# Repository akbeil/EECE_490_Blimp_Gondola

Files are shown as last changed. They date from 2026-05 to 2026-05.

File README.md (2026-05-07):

# Helium Blimp Gondola

Anders Beil and Alessio Tourrilhes EECE 490B senior capstone project implementation. Project was undertaken as our senior undergraduate design project.

---
https://github.com/akbeil/EECE_490_Blimp_Gondola/blob/main/images/demo.mp4

<table align="center">
  <tr>
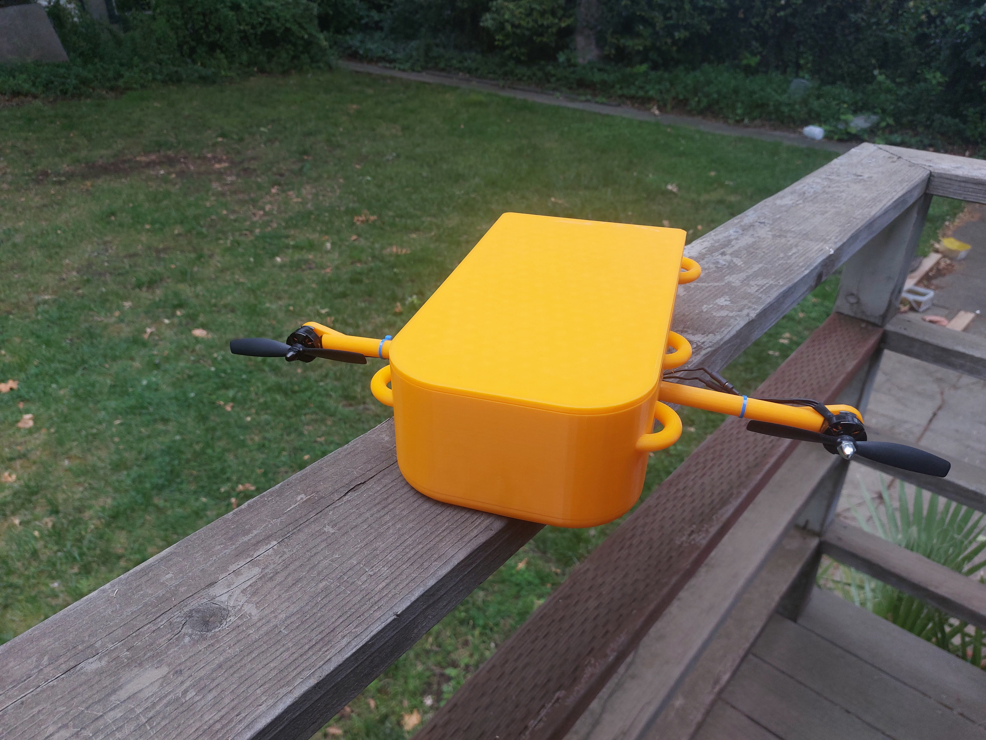
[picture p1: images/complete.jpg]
    <td></td>
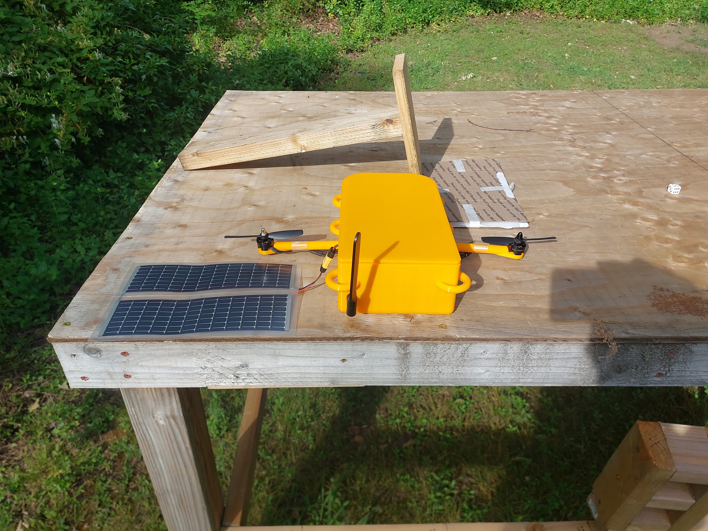
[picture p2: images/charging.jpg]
    <td></td>
  </tr>
  <tr>
    <td></td>
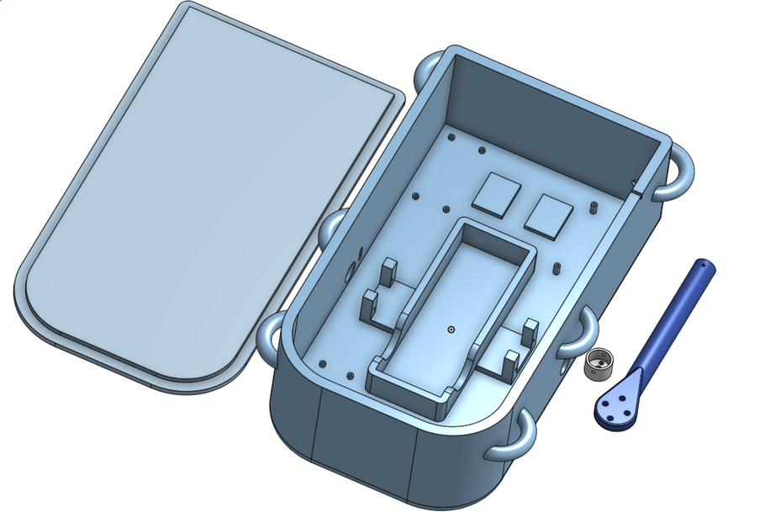
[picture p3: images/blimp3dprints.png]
    <td></td>
  </tr>
</table>

## Table of Contents
- [About](#about)
- [Features](#features)
- [Hardware](#hardware)
- [Software](#software)
- [Installation](#installation)
- [Contributors](#contributors)
---

## About

Current unmanned aerial vehicles (UAVs) have a gap in their capabilities. Drones are inexpensive but have limited flight duration, winged UAVs have longer flight times but come at a high cost. A small blimp UAV bridges this gap by being both affordable and capable of long duration flight. This blimp could be used for wildfire mapping, post-disaster search operations, or general area monitoring.

This projects object was to make the gondola that could then be attached to a blimp to be used as a surveilance blimp.

---

## Features

- Remote operation
- Receive commands via wireless LTE
- Magnetometer
- Image capture
- Configurable camera
- Battery powered with solar recharging
- Return home capeability 

---

## Hardware

Hardware needed to replicate project.
- Adafruit Ultimate GPS Breakout - PA1616S
- BNO055 9-axis Sensor
- Brushless ESC 2S 20A Electric Speed Controller
- CN3722 Solar MPPT Charger
- FEICHAO 2204 2300KV Brushless Motors
- Jx-2s-Jh10 BMS Board
- MG90D 270 Degree Servo Motors
- PCA9685 Servo Driver
- Raspberry Pi Camera Module 3
- Raspberry Pi Zero 2 W
- RC7.2-75 PSAF Solar Panels
- SIM7600G-H 4G HAT (B)
- Turnigy Rapid 2S2P 8000mAh Lipo Battery

Refer to gondola system layout in documents to build.

---

## Software

- Python 3
- adafruit_bno055
- adafruit_pca9685
- pygeomag
- pynmea2
- RClone
- rpicam
- mmcli

---

## Installation

OS settings
Ensure ModemManager Active
```bash
sudo systemctl enable ModemManager
sudo systemctl start ModemManager
```

In raspi-config
```bash
sudo raspi-config
```
Options:
Interface options
- ssh enabled
- I2C Enabled
- Serial port
  - The serial login shell is disabled
  - The serial interface is enabled

Create a venv to be able to use adafruit packages
```bash
python3 -m venv venv
source venv/bin/activate
```
install packages
```bash
sudo apt install rclone
sudo apt install modemmanager
sudo apt install libcamera-apps

pip install adafruit-blinka
pip install smbus2
pip install adafruit-circuitpython-bno055
pip install adafruit-circuitpython-pca9685
pip install pygeomag
pip install pynmea2
```

Make services for sripts to be ran automaticaly on startup
```bash
cd /etc/systemd/system/
nano servicename.service
```
Make 1 for each file thrustvector.py, recvfinal.py, and uploadfinal.py
```ini
Description=Blimp Startup Script
After=network.target

[Service]
User=<USER>
WorkingDirectory=<SCRIPT DIRECTORY>
ExecStart=<VENV PATH> <SCRIPT PATH>
Restart=always

[Install]
WantedBy=multi-user.target
```
Refer to test plan in documents to test components.

### Clone the Repository

```bash
git clone https://github.com/akbeil/EECE_490_Blimp_Gondola.git
```
## Contributors

- Anders Beil
     - akbeil@csuchico.edu  
- Alessio Tourrilhes
     - atourrilhes@csuchico.edu
     
### Advisor 
- Dr. Reza Khani
     - mkhani@csuchico.edu

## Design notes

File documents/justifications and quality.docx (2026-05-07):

Pi Zero 2W:

This is the microcontroller we chose. We chose it because it had enough ports for all the peripherals we need. Also it has good computational power for taking and compressing pictures as well as managing the control loops, while having reasonable power consumption.

Quality: satisfactory

Camera:

The camera is the central data component of our blimp and it must be working properly to be able to transmit the pictures we take from the gondola. Before the pictures are transmitted we want the camera to function properly. The camera is capable of capturing images in different resolutions and different compression quality. Both of these must be working to ensure that images the blimp captures are adjustable and able to be set how we want.

Quality: satisfactory

Solar Panels and MPPT charger:

The solar panels provide voltage to the charger, which charges the battery. This greatly extends the flight time.

Quality: passable, the charging is somewhat less than we had calculated

Brushless Motors:

The brushless motors and esc that control them are how the blimp navigates. They must be functioning correctly in order for the blimp to maneuver.

Quality: satisfactory

Servo Motors:

The servos control the orientation of the motors

Quality: satisfactory

LTE Board:

Cellular LTE is the main connection of the blimp while it is operating. It is how we will control the blimp and send commands to set settings and run programs. It is also how we upload data from the blimp, each image and then the metadata which include our gps location when the picture was taken.

Quality: satisfactory

BMS Board:

This board protects the battery from overcharge and undercharge. It also provides balanced charging from the MPPT charger.

Quality: problematic, the board is rated for 8a but the system requires more. There's no issues aside from motor start up delay.

GPS Board:

The gps is used to get the global position of the blimp, as well as altitude from sea level. It is critical for autonomous flight.

Quality: satisfactory

9 Axis Attitude Sensor:

The gyroscope is used to monitor the position, heading, and acceleration of the blimp. It uses a 3-axis accelerometer, 3-axis gyroscope, and 3-axis magnetometer. The most important part is the Euler angle which gives the direction the blimp is facing with respect to magnetic north. When combined with the gps the blimp knows where it is, and how it's moving.

Quality: satisfactory

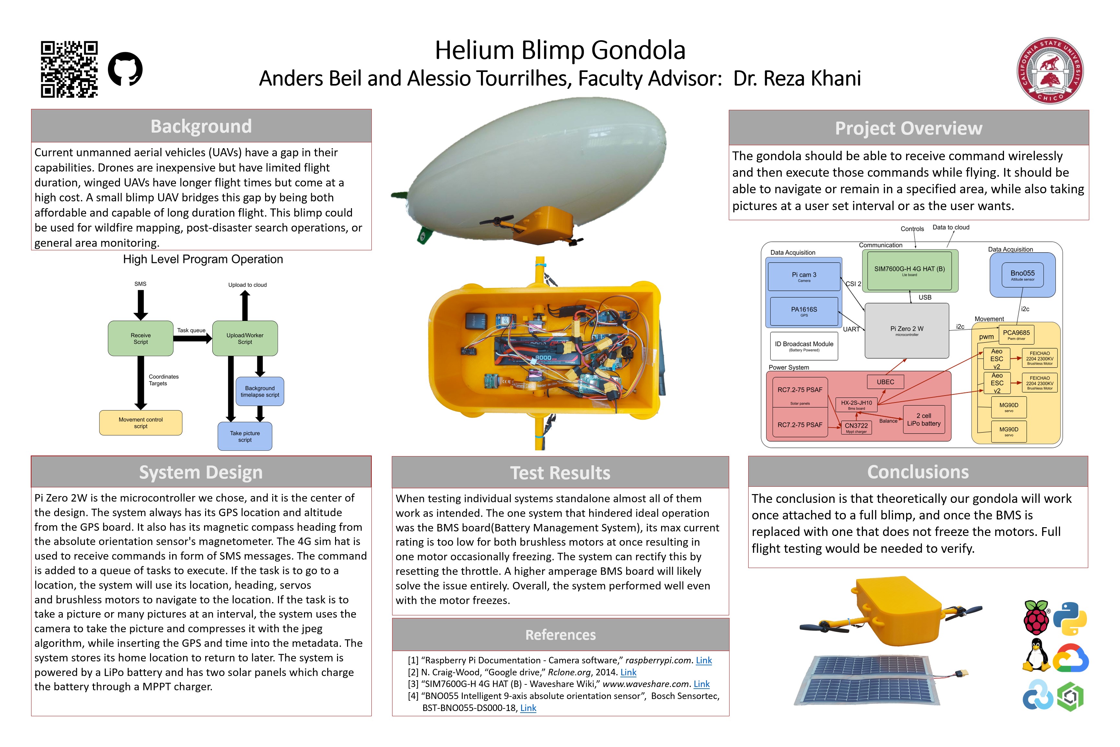
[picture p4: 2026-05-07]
documents/Slide1.jpg

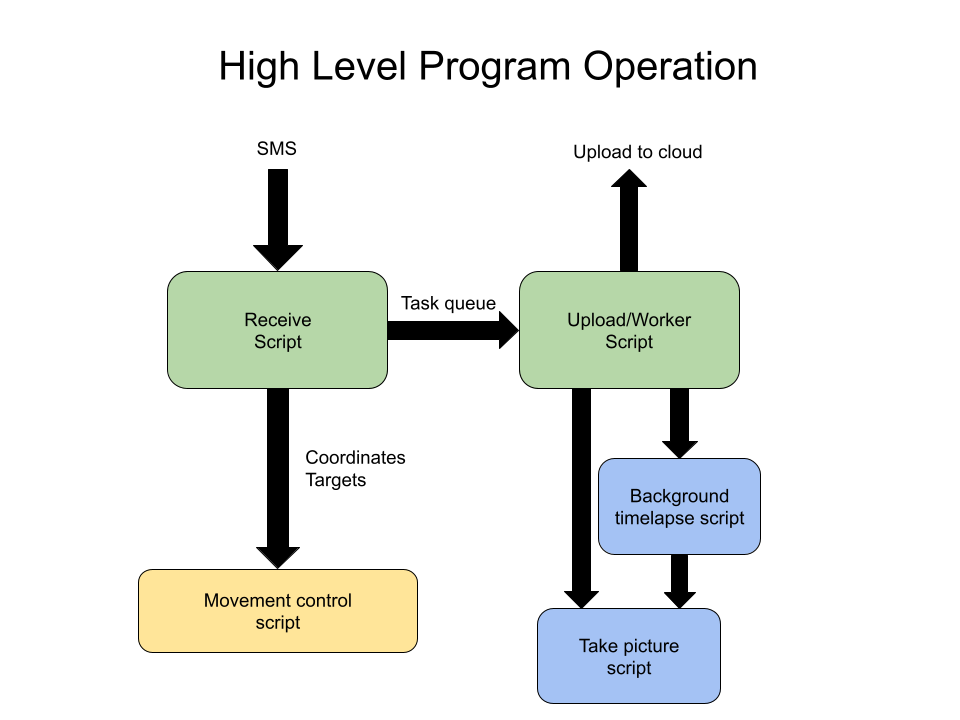
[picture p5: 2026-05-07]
documents/basic flowchart.png

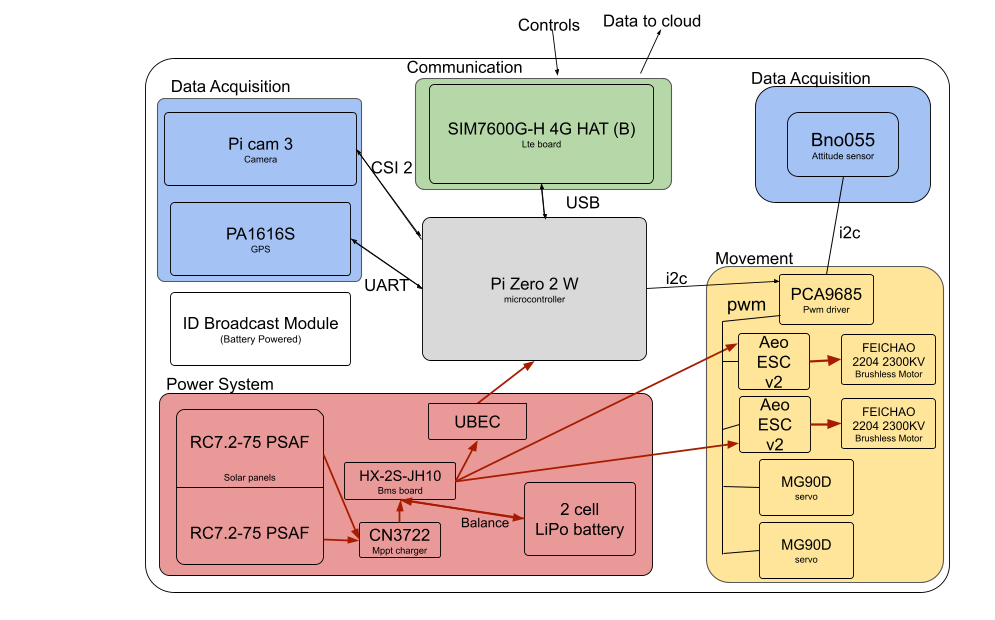
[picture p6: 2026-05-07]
documents/Gondola System Layout.png

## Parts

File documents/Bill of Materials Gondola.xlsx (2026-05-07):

Product | Quantiy | Price | Shipping | Website | Link
Adafruit Ultimate GPS Breakout - PA1616S | 1 | $29.95 | $5.80 | Adafruit | https://www.adafruit.com/wishlists/615395
Raspberry Pi Camera Module 3 | 1 | $31.99 | $0.00 | Adafruit | https://www.adafruit.com/wishlists/615395
CN3722 Solar MPPT Charger | 1 | $18.75 | $0.00 | Aliexpress | https://www.aliexpress.us/item/3256809700002675.html
SIM7600G-H 4G HAT (B) | 1 | $75.99 | $0.00 | Amazon | https://www.amazon.com/hz/wishlist/ls/3VE4V32JTM8RV?ref_=wl_share
Raspberry Pi Zero 2 W | 1 | $30.49 | $0.00 | Amazon | https://www.amazon.com/hz/wishlist/ls/3VE4V32JTM8RV?ref_=wl_share
Holy Stone FAA Compliant Remote Identification broadcast Module | 1 | $34.99 | $0.00 | Amazon | https://www.amazon.com/hz/wishlist/ls/3VE4V32JTM8RV?ref_=wl_share
3A 5V DC-DC Converter Step Down UBEC | 1 | $11.69 | $0.00 | Amazon | https://www.amazon.com/hz/wishlist/ls/3VE4V32JTM8RV?ref_=wl_share
Brushless ESC 2S 20A Electric Speed Controller | 2 | $18.99 | $0.00 | Amazon | https://www.amazon.com/hz/wishlist/ls/3VE4V32JTM8RV?ref_=wl_share
jx-2s-jh10 | 1 | $3.10 | $4.56 | AliExpress | https://www.aliexpress.us/item/3256804777549651.html
Turnigy Rapid 2S2P 8000mAh 7.4V 140C Lipo Battery | 1 | $20.60 | $10.02 | Hobby King | https://hobbyking.com/en_us/turnigy-rapid-8000mah-2s2p-140c-hardcase-lipo-battery-pack-roar-approved.html
RC7.2-75 PSAF | 2 | $19.99 | $7.03 | SolarMade | https://solarmade.com/checkouts/cn/hWN6YXK4aPnbgFvkiqrQm368/en-us
Teyleten Robot BNO055 9-Axis Attitude Sensor Module | 1 | $15.88 | $0.00 | Amazon | https://www.amazon.com/dp/B0D47G672B?ref=ppx_yo2ov_dt_b_fed_asin_title
MG90D 9g Digital Micro RC Servo Full Metal Gear 270 Degree | 2 | $4.25 | $0.00 | Amazon | https://www.amazon.com/dp/B0D5YBL2JX?ref=ppx_yo2ov_dt_b_fed_asin_title
FEICHAO 2204 2300KV Brushless Motor | 2 | $7.03 | $0.00 | Amazon | https://www.amazon.com/dp/B088K82Q46?ref=ppx_yo2ov_dt_b_fed_asin_title&th=1
 | items | 373.945
 | tax 9.25% | 34.59
 | shipping |  | $27.41
 | total | $435.94
RockBLOCK 9704 | 1 | $274.95 | $0.00 | SparkFun | https://www.sparkfun.com/rockblock-9704-patch-antenna.html
 | items | 648.895
 | tax 9.25% | 60.02
 | shipping |  | $27.41
 | total | $736.33

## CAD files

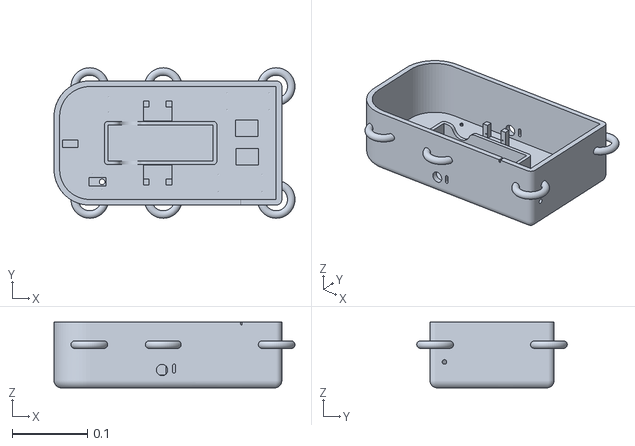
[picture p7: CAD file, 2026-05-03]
3d models/Gondola.stl
0.32 x 0.2 x 0.0875

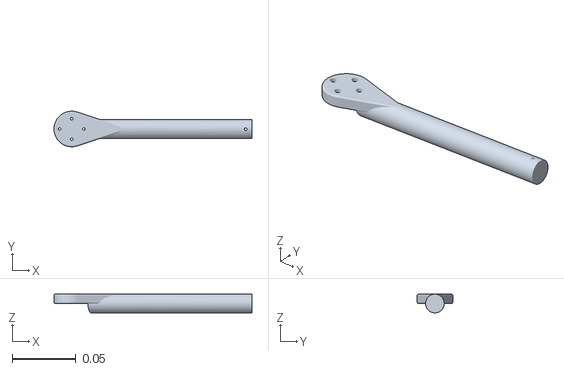
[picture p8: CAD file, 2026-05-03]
3d models/pole.stl
0.155 x 0.028 x 0.0148

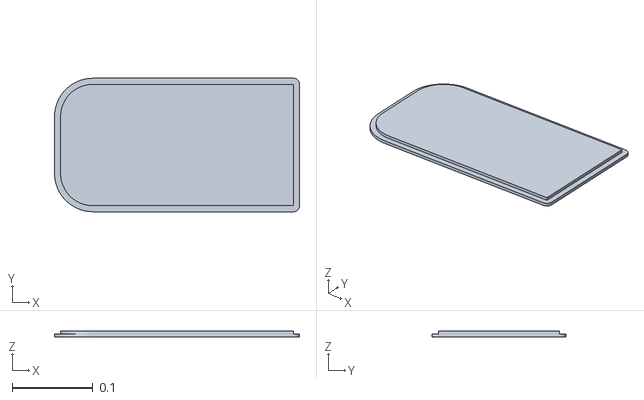
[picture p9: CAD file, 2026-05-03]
3d models/Lid.stl
0.303 x 0.165 x 0.0075

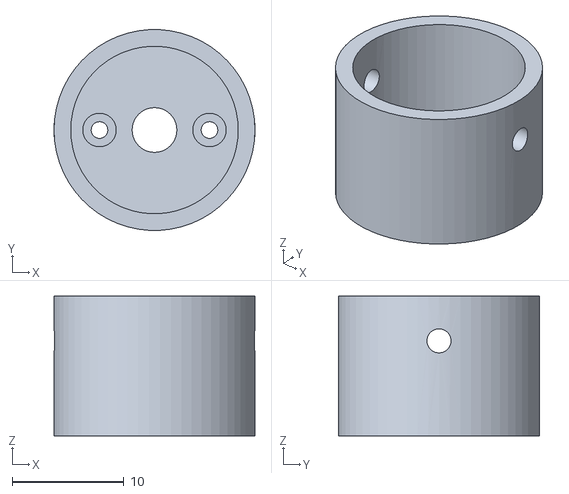
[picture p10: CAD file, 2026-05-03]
3d models/Servo attachment.stl
18.0 x 18.0 x 12.5

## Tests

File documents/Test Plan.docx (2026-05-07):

Test #1 Camera

The camera is the central data component of our blimp and it must be working properly to be able to transmit the pictures we take from the gondola. Before the pictures are transmitted we want the camera to function properly. The camera is capable of capturing images in different resolutions and different compression quality. Both of these must be working to ensure that images the blimp captures are adjustable and able to be set how we want.

Materials Needed for Test:

- Raspberry Pi Zero 2 W
- Raspberry Pi Camera Module 3
- Command Prompt / Pi Connect

Performing the Test:

1. The first thing that must be done for the test is to connect to the pi, either by ssh or Pi Connect.

ssh blimp26@RASPBERRY_PI's_IP_ADDRESS

2. Next ensure that you are in the correct directory with

cd /home/blimp26/0405

3. There are 3 parameters for takepic.py. The first is resolution which can be set to 720, 1080, or 4k. The second is quality that can be set from 0-100 and control the compression of the image. Closer to 0 gets you a smaller file size but at the cost of image quality. And the reverse for closer to 100.

python3 takepic.py 720|1080|4k quality filename.jpg

4. We will want to ensure that all levels of resolution work with a range of compressions
5. First we can do.

python3 takepic.py 720 100 testcamera720_100.jpg

6. Next do.

python3 takepic.py 720 50 testcamera720_50.jpg

7. Lastly for 720p.

python3 takepic.py 720 25 testcamera720_25.jpg

8. We will use SFTP as an easy way to transfer files from the pi to a separate computer for viewing as the pi is headless and must be accessed via SSH. First connect to pi from laptop using

sftp blimp26@RASPBERRY_PI's_IP_ADDRESS

9. Using SFTP is like using linux commands, ls, cd, pwd, mkdir, rm, rmdir all work, using this navigate to the folder where picture were taken in this case

ls

cd 0405

10. Then using SFTP from a computer we can transfer the image to a device that has a visual interface to inspect the images visually to see the difference in image quality while also inspecting the image size. Once you are in the directory of files you want then you just get and specify where you want to put the file on the computer and it transfers the file.

get [directory/file on pi] [local directory]

get testcamera720_25.jpg C:/user/Pictures

11. Repeat step 10 for all images taken.
12. Then repeat steps 5 through 11 for resolutions of 1080p and 4k. Those commands would be as follows for 1080p.

python3 takepic.py 1080 100 testcamera1080_100.jpg

python3 takepic.py 1080 60 testcamera1080_60.jpg

python3 takepic.py 1080 20 testcamera1080_20.jpg

get testcamera1080_100.jpg C:/user/Pictures

get testcamera1080_60.jpg C:/user/Pictures

get testcamera1080_20.jpg C:/user/Pictures

13. And commands for 4k would be as follows.

python3 takepic.py 4k 100 testcamera4k_100.jpg

python3 takepic.py 4k 65 testcamera4k_65.jpg

python3 takepic.py 4k 30 testcamera4k_30.jpg

get testcamera4k_100.jpg C:/user/Pictures

get testcamera4k_65.jpg C:/user/Pictures

get testcamera4k_30.jpg C:/user/Pictures

14. And quality can be used across all 3 resolutions. We are just trying to ensure that quality works across all 3 and compression works to compress images and give us a smaller file and then can see the difference in quality of different compression levels.
15. End of Test.

Results:

Camera is able to be configured and a wide range of resolutions and quality are able to be produced, leading to a successful system that serves our needs for next block of the system.

Script: takepic.py

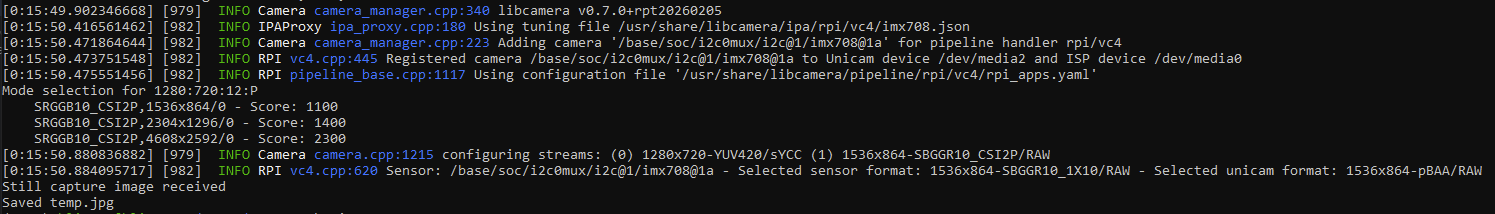
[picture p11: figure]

Test #2 Solar Pannel

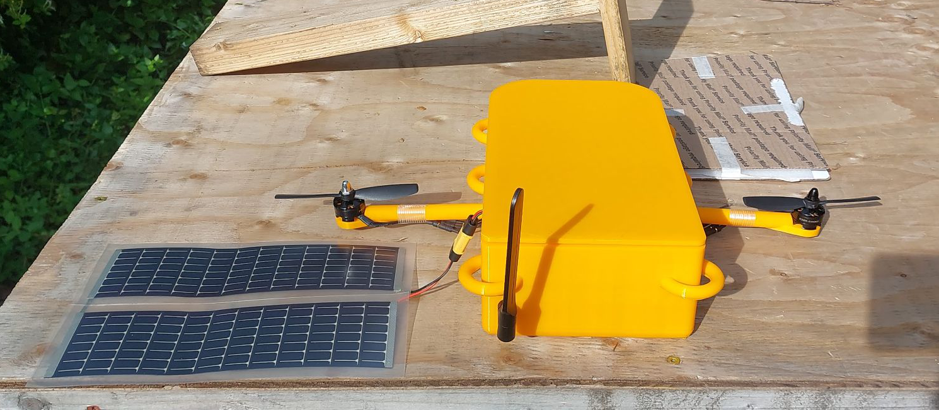
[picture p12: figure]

Materials Needed for Test:

- 2x of RC7.2-75 PSAF in Series
- CN3722 Solar MPPT Charger
- Multi Meter

Performing the Test:

1. First ensure that solar panels in series are working and giving an output. VOC = 11.1V and Operating voltage is 7.2v so depending on the sun levels ensure that the voltage is between 14.4V-22.2V. If covering the panel reduces voltage then the panel is operating correctly. The more sun the higher the voltage should be.
2. Connect solar panel. If there is no output, counterclockwise adjust the MPPT pot until voltage appears.

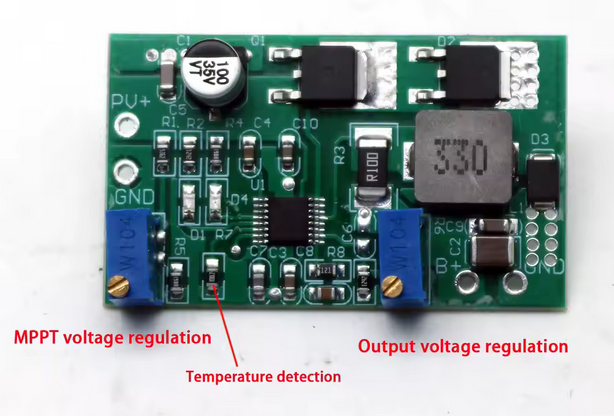
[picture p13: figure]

3. Counterclockwise adjust output pot until LEDs blink, then set to the battery’s max voltage of 8.4V.
4. Connect battery + ammeter. Fine-tune MPPT pot for max current (or match solar panel’s nominal voltage).
5. Verify cutoff voltage with multimeter and adjust output pot if needed.
6. End Test.

Results:

The MPPT board outputs 8.4V which will allow the battery to be trickle charged to extend the duration of the gondola’s operation.

Test #3 Motors

The brushless motors and esc that control them are how the blimp navigates. They must be functioning correctly in order for the blimp to maneuver.

Materials Needed for Test:

- Raspberry Pi Zero 2 W
- 2x of FEICHAO 2204 2300KV Brushless Motor
- 2x of EPower 20A 2S ESC
- PCA9685 I2C PWM board
- Command Prompt / Pi Connect
1. The first thing that must be done for the test is to connect to the pi, either by ssh or Pi Connect.
2. Next ensure that you are in the correct directory with

cd /home/blimp26/blimp_venv

3. Next activate the virtual python environment if not already active

source venv/bin/activate

4. The pwm board allows control of many pwm outputs using i2c
5. The test script allows to test the motors
  a. Set motors to MINIMUM to arm the ESCs

If not, entering program mode is possible

if that is the case, do not change throttle level and disconnect ESCs

  b. After the 12 123 beep chime you can test freely

Script: python programesc.py

6. End Test.

Results:

The motors' full range of rpms are accessible and working as intended. This allows us to control the blimp as we desire and at more specific throttle levels than this test if we choose to.

Test #4 Servo Motors

The servos control the orientation of the motors

Materials Needed for Test:

- Raspberry Pi Zero 2 W
- 2x of MG90D 270° Servo Motors
- PCA9685 I2C PWM board
- Command Prompt / Pi Connect
1. The first thing that must be done for the test is to connect to the pi, either by ssh or Pi Connect.
2. Next ensure that you are in the correct directory with

cd /home/blimp26/blimp_venv

3. Next activate the virtual python environment if not already active

source venv/bin/activate

4. The test script allows to test the servos
  a. The ESCs need to be plugged in as they provide power to the servos

Script: python servoctrl.py

5. End of test

Results

The servo motors can move the arms adequately and have good precision. They can be set to any point in 270 degrees of rotation.

Test #5 LTE

Cellular LTE is the main connection of the blimp while it is operating. It is how we will control the blimp and send commands to set settings and run programs. It is also how we upload data from the blimp, each image and then the metadata which include our gps location when the picture was taken.

Materials Needed for Test:

- Raspberry Pi Zero 2 W
- SIM7600G-H 4G HAT (B)
- Command Prompt / Pi Connect
1. The first thing that must be done for the test is to connect to the pi, either by ssh or Pi Connect.
2. The modem manager and network manager automatically detect the lte board and configure the network interface.
3. If needed it can be done manually with the following commands and qmi command line interface
  a. sudo systemctl disable ModemManager
  b. sudo qmicli -d /dev/cdc-wdm0 --wds-start-network="apn=simbase,ip-type=4" --client-no-release-cid
  c. sudo qmicli -d /dev/cdc-wdm0 --wds-get-current-settings --client-no-release-cid --client-cid=[cid]
  d. sudo ip link set dev wwan0 up
  e. sudo ip a add [addr] dev wwan0 metric 700
  f. sudo ip route add default via [gate] dev wwan0 metric 700
4. Check the modemmanager assigned an ip correctly

Command: ip address

5. Check the status of the connection

Command: mmcli -m 0

6. Test the connection by pinging using the lte network interface

ping -I wwan0 -c 1 8.8.8.8

7. End of test

Results

Modem manager is correctly set up to automatically configure the lte/wwan0 network interface, and transmission speed and latency are acceptable.

Test #6 Gps

The gps is used to get the global position of the blimp, as well as altitude from sea level. It is critical for autonomous flight.

Materials Needed for Test:

- Raspberry Pi Zero 2 W
- PA1616S GPS
- Command Prompt / Pi Connect
1. The first thing that must be done for the test is to connect to the pi, either by ssh or Pi Connect.
2. Next ensure that you are in the correct directory with

cd /home/blimp26/blimp_venv

3. Next activate the virtual python environment if not already active

source venv/bin/activate

4. The test script outputs the coordinates and altitude

Script: python gpstest.py

Taking the coordinates to google maps shows position accurately to a 5 meters. The system is in the backyard.

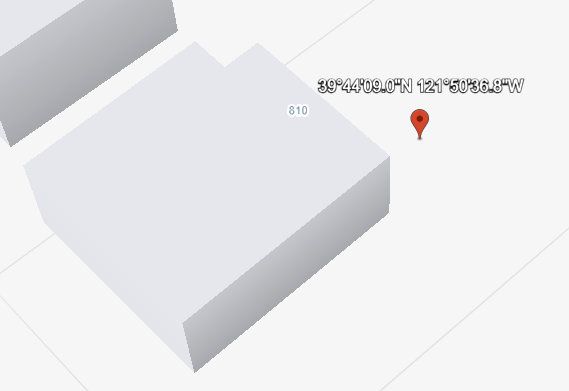
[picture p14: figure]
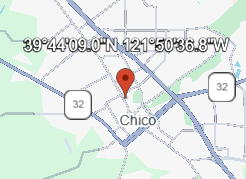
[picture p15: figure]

5. End of test

Results

The gps module is very accurate and important for the navigation of the blimp.

Test #7 9 Axis Attitude Sensor

The gyroscope is used to monitor the position, heading, and acceleration of the blimp. It uses a 3-axis accelerometer, 3-axis gyroscope, and 3-axis magnetometer. The most important part is the euler angle which gives the direction the blimp is facing with respect to magnetic north. When combined with the gps the blimp knows where it is, and how it's moving.

Materials Needed for Test:

- Raspberry Pi Zero 2 W
- BNO055 Absolute Orientation Sensor
- Command Prompt / Pi Connect
1. The first thing that must be done for the test is to connect to the pi, either by ssh or Pi Connect.
2. Next ensure that you are in the correct directory with

cd /home/blimp26/blimp_venv

3. Next activate the virtual python environment if not already active

source venv/bin/activate

4. The test script outputs all the data the bno055 collects

Script: python bno055test.py

The board needs to be moved around briefly for it to calibrate.

The first number of euler angle, which is the surface plane angle relative to north, is accurate to a couple of degrees.

5. End of test

Results

The bno055 is very accurate and important for the navigation of the blimp.

Test #8 Cloud upload

Materials Needed for Test:

- Raspberry Pi Zero 2 W
- Command Prompt / Pi Connect
1. The first thing that must be done for the test is to connect to the pi, either by ssh or Pi Connect.
2. Next ensure that you are in the a directory with a file
3. The rclone command is used to upload files to the google cloud folder. The -v tag is to show a verbose output of the command.

Command: rclone copy [file name] blimp26:/BlimpImages -v

The file correctly appears in the cloud folder

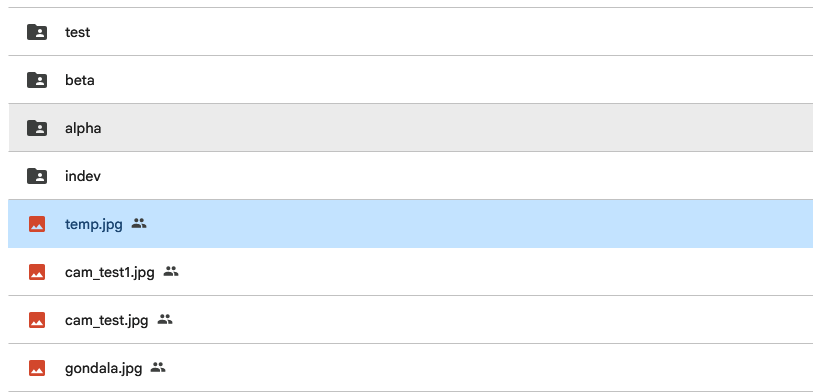
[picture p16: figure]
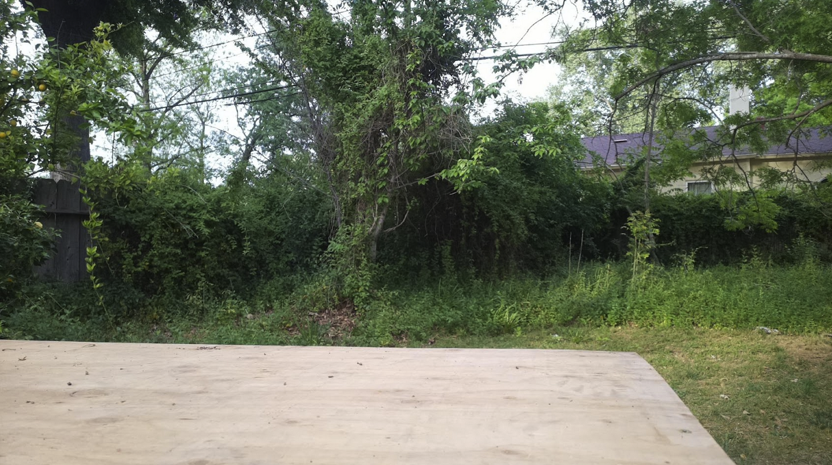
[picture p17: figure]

4. End of test

Results

The file is transferred accurately over lte to the cloud folder.

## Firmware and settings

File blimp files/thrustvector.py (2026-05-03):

import math
import time
import board
import busio
import serial
import pynmea2
from adafruit_bno055 import BNO055_I2C
from adafruit_pca9685 import PCA9685
from pygeomag import GeoMag
geomag = GeoMag()

GPS_PORT = "/dev/serial0"
GPS_BAUD = 9600
GPS_TIMEOUT = 10

SERVO_NEUTRAL = 1500
SERVO_MIN = 500
SERVO_MAX = 2500
DEADBAND = 5

SERVO_CH = [7, 8]
ESC_CH = [0, 1]

PCA_FREQ = 50 # Hz for standard servos / ESCs

def get_latest_gps(ser):
    """read latest GPS fix"""
    while ser.in_waiting:
        line = ser.readline().decode(errors="ignore").strip()

        if line.startswith("$GPGGA"):
            try:
                msg = pynmea2.parse(line)
                if int(msg.gps_qual) > 0:
                    return {
                        "lat": msg.latitude,
                        "lon": msg.longitude,
                        "alt": float(msg.altitude)
                    }
            except Exception:
                pass

    return None

def get_bearing(lat1, lon1, lat2, lon2):
    """get bearing from point 1 to point 2 in degrees (0-360)"""
    lat1 = math.radians(lat1)
    lat2 = math.radians(lat2)
    dlon = math.radians(lon2 - lon1)

    x = math.sin(dlon) * math.cos(lat2)
    y = math.cos(lat1)*math.sin(lat2) - math.sin(lat1)*math.cos(lat2)*math.cos(dlon)

    bearing = math.degrees(math.atan2(x, y))
    return (bearing + 360) % 360

def heading_error(target, current):
    """compute heading error (-180 to 180)"""
    error = target - current
    if error > 180:
        error -= 360
    elif error < -180:
        error += 360
    return error

def distance_m(lat1, lon1, lat2, lon2):
    """distance between two lat/lon points in meters"""
    R = 6371000  # Earth radius (m)

    lat1 = math.radians(lat1)
    lat2 = math.radians(lat2)
    dlat = lat2 - lat1
    dlon = math.radians(lon2 - lon1)

    a = math.sin(dlat / 2)**2 + math.cos(lat1) * math.cos(lat2) * math.sin(dlon / 2)**2
    c = 2 * math.atan2(math.sqrt(a), math.sqrt(1 - a))

    return R * c

def thrust_vector_control(error, alt_error, pca):
    abs_err = abs(error)
    direction = 1 if error > 0 else -1  # +1 = right turn, -1 = left

    base_throttle = 1100
    min_throttle = 1000
    max_throttle = 1200
    forward = 32

    if alt_error > 5:
        forward = 17
    elif alt_error < -5:
        forward = 47
    else:
        forward = 32

    # straight
    if abs_err <= 10:
        set_servo_pair(forward, pca)
        set_pulse(ESC_CH, base_throttle, pca)
        return

    # 10 to 90
    elif abs_err <= 90:
        #t = (abs_err - 10) / (90 - 10)  # 0 → 1

        active = base_throttle
        reduced = 1000 #base_throttle - t * (base_throttle - min_throttle)

        set_servo_pair(forward, pca)

        if direction > 0:
            # turn right
            set_pulse(ESC_CH[0], active, pca)
            set_pulse(ESC_CH[1], reduced, pca)
        else:
            # turn left
            set_pulse(ESC_CH[0], reduced, pca)
            set_pulse(ESC_CH[1], active, pca)

        return

    # 90 to 180
    else:
        #t = (abs_err - 90) / (180 - 90)  # 0 → 1

        #ramp = min_throttle + t * (max_throttle - min_throttle)

        if direction > 0:
            # turn right
            set_pulse(ESC_CH[0], base_throttle, pca)
            set_pulse(ESC_CH[1], base_throttle, pca)

            set_pulse(SERVO_CH[1], 2500, pca)
            set_pulse(SERVO_CH[0], 2500-2000*0.32, pca)

        else:
            # turn left
            set_pulse(ESC_CH[0], base_throttle, pca)
            set_pulse(ESC_CH[1], base_throttle, pca)

            set_pulse(SERVO_CH[0], 500, pca)
            set_pulse(SERVO_CH[1], 2000*0.32+500, pca)

        return

def set_pulse(channels, pulse_us, pca):
    """Set PWM pulse width for PCA9685"""
    duty = int(pulse_us / (1000000 / PCA_FREQ) * 65535)
    if isinstance(channels, int):
        pca.channels[channels].duty_cycle = duty
    else:
        for ch in channels:
            pca.channels[ch].duty_cycle = duty

servo_ch = [7,8]
def set_servo_pair(percent, pca):
    """set both servos to a percent 0 down 100 backwards"""
    percent = max(0, min(100, percent))

    min_pulse = 500
    max_pulse = 2500
    step = (max_pulse - min_pulse) / 100

    pulse1 = int(min_pulse + percent * step)
    pulse2 = int(max_pulse - percent * step)

    pca.channels[servo_ch[1]].duty_cycle = int(pulse1 / 20000 * 65535)
    pca.channels[servo_ch[0]].duty_cycle = int(pulse2 / 20000 * 65535)

def main():
    TARGET_LAT = None
    TARGET_LON = None
    TARGET_ALT = None
    TARGET_RAD = None
    HOME_LAT = None
    HOME_LON = None
    HOME_ALT = None

    # i2c
    i2c = busio.I2C(board.SCL, board.SDA)

    # bno055
    sensor = BNO055_I2C(i2c, address = 0x29)
    sensor.mode = 12

    # pca9685
    pca = PCA9685(i2c, address = 0x40)
    pca.frequency = PCA_FREQ

    # gps
    ser = serial.Serial(GPS_PORT, GPS_BAUD, timeout=0.2)

    # bno055
    while not ((sensor.calibration_status[3] == 3) & (sensor.calibration_status[0] == 3)):
        print("mag status: ", sensor.calibration_status[3], ", sys status: ", sensor.calibration_status[0])
        time.sleep(0.5)

    print("starting nav loop")
    set_servo_pair(31, pca)
    time.sleep(0.5)
    set_servo_pair(32, pca)
    set_pulse(ESC_CH, 1000, pca)
    time.sleep(5)
    booldec = False
    head_error = 9999
    declination = 0
    check = 10

    while True:
        gps = get_latest_gps(ser)
        if gps is None:
            print("no gps")
            time.sleep(1)
            continue
        
        # set home coords
        if gps is not None and HOME_LAT is None:
            HOME_LAT = gps["lat"]
            HOME_LON = gps["lon"]
            HOME_ALT = gps["alt"]
            with open("home.txt", "w") as h:
                h.write(f"{HOME_LAT},{HOME_LON},{HOME_ALT}")
            print("home set:", HOME_LAT, HOME_LON, HOME_ALT)

        # calculate declination
        if gps is not None and (not booldec):
            declination = geomag.calculate(gps["lat"], gps["lon"], gps["alt"], 2026.25).dec
            print ("declination: ", declination)
            booldec = True
        
        mag_heading = sensor.euler[0]
        
        if mag_heading is None:
            print("waiting for bno heading")
            time.sleep(0.1)

        # no gps for 5sec stop motors
        last_valid_time = time.time()
        if gps:
            last_valid_time = time.time()

        if time.time() - last_valid_time > 5:
            print("failsafe: stopping motors")
            set_pulse(ESC_CH, 1000, pca)
        
        # check for updates to target file
        if (check > 10):
            check = 0
            try:
                with open("target.txt") as f:
                    line = f.read().strip()

                    if not line:
                        # Empty file → clear target
                        TARGET_LAT = None
                        TARGET_LON = None
                        TARGET_ALT = None
                        TARGET_RAD = None
                        print("Target cleared (empty file)")
                    else:
                        print("setting local target vars\n")
                        lat, lon, alt, rad = map(float, line.split(","))
                        TARGET_LAT, TARGET_LON, TARGET_ALT, TARGET_RAD = lat, lon, alt, rad

            except Exception as e:
                print("Bad target file:", e)
        check = check + 1

        # main part if there is a target to go to
        if TARGET_LAT is not None:
            alt_error = gps["alt"] - TARGET_ALT

            if sensor.calibration_status[3] >= 2:
                current_heading = (mag_heading + declination + 360) % 360
                target_heading = get_bearing(gps["lat"], gps["lon"], TARGET_LAT, TARGET_LON)
                head_error = heading_error(target_heading, current_heading)

                print(f"GPS: ({gps['lat']:.5f},{gps['lon']:.5f}) | "
                f"Heading: {current_heading:.1f}° | "
                f"Target: {target_heading:.1f}° | "
                f"Error: {head_error:.1f}° | "
                f"Altitude: {gps['alt']}m |")
            else:
                print("mag < 2")

            # if at target adjust alt if needed
            if (distance_m(gps["lat"], gps["lon"], TARGET_LAT, TARGET_LON) < TARGET_RAD): 
                print("at location")
                if alt_error > 5: # straight down
                    set_servo_pair(0, pca)
                    set_pulse(ESC_CH, 1100, pca)
                elif alt_error < -5: # straight up
                    set_servo_pair(67, pca)
                    set_pulse(ESC_CH, 1100, pca)
                else: # off
                    set_pulse(ESC_CH, 1000, pca)
                    time.sleep(2)
            else:
                print("going")
                thrust_vector_control(head_error, alt_error, pca)
        else: # off
            print("no target")
            set_pulse(ESC_CH, 1000, pca)
            set_servo_pair(32, pca)

        time.sleep(1)


if __name__ == "__main__":
    main()

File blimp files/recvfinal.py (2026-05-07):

import subprocess
import time
import os
import re

QUEUE_FILE = "./queue.txt"
MODEM_ID = "0"

def run_mmcli(args): # to run mmcli cmds
    result = subprocess.run(
        ["mmcli"] + args,
        capture_output=True,
        text=True
    )
    return result.stdout

def list_sms(): # list sms messages
    out = run_mmcli(["-m", MODEM_ID, "--messaging-list-sms"])
    return re.findall(r'/SMS/(\d+)', out)

def read_sms(sms_id):
    return run_mmcli(["-s", sms_id])

def delete_sms(sms_id): # to delete after reading
    subprocess.run([
        "sudo",
        "mmcli",
        "-m", MODEM_ID,
        f"--messaging-delete-sms={sms_id}"
    ])

def parse_sms_text(raw): # parser
    for line in raw.splitlines():
        if "text:" in line.lower():
            return line.split(":", 1)[1].strip()
    return None

def safe_enqueue(line): # safe
    with open(QUEUE_FILE, "a") as f:
        f.write(line + "\n")
        f.flush()
        os.fsync(f.fileno())

def safe_prequeue(line):
    # Read existing content (if file exists)
    if os.path.exists(QUEUE_FILE):
        with open(QUEUE_FILE, "r") as f:
            existing = f.read()
    else:
        existing = ""

    # Write new line at the beginning
    with open(QUEUE_FILE, "w") as f:
        f.write(line + "\n" + existing)
        f.flush()
        os.fsync(f.fileno())


def handle_command(command_text):
    command_text = command_text.strip().lower()
    print("\x1b[1;31m")
    print("Received command:", command_text)

    parts = command_text.split()

    if not parts:
        return

    if parts[0] == "takepic":
        safe_enqueue("TAKEPIC")

    elif parts[0] == "takepics":
        if len(parts) == 3:
            safe_enqueue(f"TAKEPICS {parts[1]} {parts[2]}")
        else:
            print("\x1b[1;31m")
            print("Invalid TAKEPICS format")

    elif parts[0] == "goto":
        if len(parts) >= 5:
            lat, lon, alt, radius = parts[1], parts[2], parts[3], parts[4]
            safe_prequeue(f"GOTO {lat} {lon} {alt} {radius}")
        else:
            print("\x1b[1;31m")
            print("Invalid GOTO format")

    elif parts[0] == "stop":
        safe_prequeue("STOP")

    elif parts[0] == "reboot":
        safe_enqueue("REBOOT")

    elif parts[0] == "home":
        safe_prequeue("HOME")

    elif parts[0] == "picset":
        if len(parts) == 3:
            safe_prequeue(f"PICSET {parts[1]} {parts[2]}")
        else:
            print("\x1b[1;31m")
            print("Invalid PICSET format")

    else:
        print("\x1b[1;31m")
        print("Unknown command")


def main():
    print("\x1b[1;31m")
    print("Polling for SMS via mmcli...\n")

    seen = set()

    while True:
        sms_ids = list_sms()

        for sms_id in sms_ids:
            if sms_id in seen:
                continue

            print("\x1b[1;31m")
            print("New SMS:", sms_id)

            raw = read_sms(sms_id)
            print("\x1b[1;31m")
            print(raw)

            text = parse_sms_text(raw)

            if text:
                handle_command(text)

            delete_sms(sms_id)
            seen.add(sms_id)

        time.sleep(5)  # polling interval


if __name__ == "__main__":
    main()

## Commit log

2026-05-03 added 3d modeling files
    [Gondola.stl, Lid.stl, Servo attachment.stl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]
2026-05-03 moved Gondola.stl to 3d models folder
    [Gondola.stl]
2026-05-03 moved Lid.stl to 3d models folder
    [Lid.stl]
2026-05-03 moved Servo attachment.stl to 3d models folder
    [Servo attachment.stl]
2026-05-03 moved pole.stl to 3d models folder
    [pole.stl]
2026-05-07 Rename thrustvector.py to blimp files/thrustvector.py
2026-05-07 added image of 3d print models
